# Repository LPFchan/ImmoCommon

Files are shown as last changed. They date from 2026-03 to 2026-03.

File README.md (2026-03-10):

# Immogen — Ninebot G30 BLE Immobilizer

**Immogen** is a three-part BLE immobilizer system for the Ninebot Max G30, consisting of **[Uguisu](https://github.com/LPFchan/Immogen/tree/main/Uguisu#readme)** (key fob), **[Guillemot](https://github.com/LPFchan/Immogen/tree/main/Guillemot#readme)** (deck receiver), and **[Whimbrel](https://github.com/LPFchan/Whimbrel)** (Web Serial provisioning app).

Guillemot sits inline between the battery and ESC via an XT60 splice. Without a valid BLE unlock from Uguisu, the scooter stays inoperable. Male/female pigtails keep the install reversible—no permanent modification required.

```
┌─────────────────┐       BLE advertisement        ┌──────────────────────┐
│  UGUISU (FOB)   │ ─────────────────────────────> │ GUILLEMOT (RECEIVER) │
│  XIAO nRF52840  │       (2.4 GHz, ~2 m)          │  XIAO nRF52840       │
└───────┬─────────┘                                └──────────┬───────────┘
        │                                                     │
        │                 ┌────────────────────┐              │
        └──────(USB-C)──> │ WHIMBREL (WEB APP) │ <──(USB-C)───┘
       (Provisioning)     │ Chrome / Edge      │    (Provisioning)
                          └────────────────────┘
```

## Repository Structure

| Path | Description |
| --- | --- |
| `Uguisu/` | Key fob — firmware, KiCad, BOM. Button press → 2 s BLE broadcast → sleep. [README](https://github.com/LPFchan/Immogen/tree/main/Uguisu#readme) |
| `Guillemot/` | Deck receiver — firmware, KiCad, BOM. Duty-cycled scan (5%), validates adverts → SR latch → power gate. [README](https://github.com/LPFchan/Immogen/tree/main/Guillemot#readme) |
| `lib/` | Shared C++ library: AES-128-CCM MIC, provisioning loop, LittleFS counter storage |
| `tools/` | LED visualizer, BLE timing simulator, buzzer tuner (HTML); MIC test vectors (`gen_mic.py`) |
| `logs/` | Technical writeups: architecture reviews, BLE power analysis, design decisions, migration guides, documentation reports |

## BLE Protocol

Advertisement-only; no persistent connection. Both devices share a company ID, a 2-byte magic prefix (`0x494D`), and a pre-shared key (PSK). Each advertisement carries a 13-byte payload after the manufacturer specific data header (company ID + magic):

| Offset | Size | Field | Purpose |
| --- | ---- | --- | --- |
| 0 | 4 | counter | Anti-replay, monotonic (AAD)|
| 4 | 1 | command | 0x01 = Unlock, 0x02 = Lock (Encrypted) |
| 5 | 8 | mic | AES-128-CCM auth tag |

## Quick Start

Pre-built firmware is available on the [Releases](https://github.com/LPFchan/Immogen/releases) page. Use [Whimbrel](https://github.com/LPFchan/Whimbrel) to flash and provision keys via Web Serial.

**Build from source:**

```bash
# Deck receiver
cd Guillemot/firmware && pio run

# Key fob
cd Uguisu/firmware && pio run
```

## Roadmap

- Uguisu enclosure CAD (3D print).
- First-build validation: PPK2 power, BLE range through deck, pre-charge waveform.

## Safety & Legal

- Prototype security/power-interrupt device. Use at your own risk.
- Not affiliated with Segway-Ninebot.
- **Do not test lock behavior while riding.**

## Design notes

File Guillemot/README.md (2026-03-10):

# Guillemot — Ninebot G30 BLE Immobilizer Receiver

Guillemot is the deck receiver in a three-part immobilizer system ([Uguisu](https://github.com/LPFchan/Immogen/tree/main/Uguisu) fob + [Whimbrel](https://github.com/LPFchan/Whimbrel) web app) for the Ninebot Max G30. It validates encrypted BLE advertisements from the fob and controls an SR latch that gates battery-to-ESC power via an inline XT60 splice. Male/female pigtails make it fully reversible—no permanent modification to the vehicle. Protocol and cryptography are handled by the shared [lib/](https://github.com/LPFchan/Immogen/tree/main/lib) in this monorepo ([Immogen](https://github.com/LPFchan/Immogen)).

---

## Hardware

### Placement

Mount Guillemot on the plastic underside of the deck for good 2.4 GHz RF.

### Components & BOM (~$20)

| Ref | Part | Notes | JLCPCB # | Cost |
| --- | --- | --- | --- | --- |
| U1 | XIAO nRF52840 | MCU: BLE scanning, latch control, buzzer PWM | Seeed | $8.23  |
| U2 | SN74LVC2G02DCTR | SR latch: Q = unlock. 10 nF + 100 kΩ differentiator for POR pulse | C94600 (ext.) | $0.53  |
| PS1 | TPSM365R6V3RDNR | Buck: 3–65 V in, 3.3 V/600 mA, 4 μA Iq. Feeds XIAO 3V3 directly.  | C18208843 (ext.) | $3.59  |
| Q1 | IPB042N10N3G | Main MOSFET: 100 V/137 A, D2PAK, low-side GND return | C69300 (ext.) | $0.75  |
| Q2 | AO3422 | Pre-charge FET, inrush ~0.8 A. Driven by latch Q. | C37130 (ext.) | $0.23  |
| Q3 | SI2309CDS | Bleeder P-FET: disconnects 10 kΩ bleeder when locked (0 μA) | C10493 (ext.) | $0.23  |
| Q4 | 2N7002 | Gate drive | C8545 | $0.01  |
| Q5, Q6 | MMBT3904 | Buzzer driver | C20526 | $0.02  |
| BZ1 | FUET-1230 | Buzzer: 12×12×3 mm SMD, 4 kHz. Driven by MMBT3904 | C391037 (ext.) | $0.47  |
| D1 | BZT52C12-7-F | 12 V Zener | C124196 (ext.) | $0.11  |
| D2 | BZT52C10-7-F | 10 V Zener | C155227 (ext.) | $0.10  |
| D3, D4 | 1N4148W | Gate isolation from buzzer rail sag | C81598 | $0.01  |
| D5 | SMBJ45A | 45 V TVS diode for transient suppression | C114005 (ext.) | $0.08  |
| C1 | 10 nF (0603) | POR pulse differentiator | C57112 | $0.003 |
| C2 | 100 µF (1210) | Bulk decoupling. EMK325ABJ107MM-P 16V X5R ±20% | C90143 (ext.) | $0.31  |
| C3, C4 | 1 µF (0603) | RC delay bypass, gate isolation | C15849 | $0.01  |
| R1–R3, R7 | 100 kΩ (0603) | Gate drive, pull-ups, RC delay (τ = 100 ms) | C25803 | $0.006 |
| R4 | 1 MΩ (0603) | P-FET gate pull-up | C22935 | $0.001 |
| R5 | 10 kΩ (0603) | Bleeder resistor | C25804 | $0.001 |
| R6 | 4.7 kΩ (0603) | Piezo buzzer discharge resistor | C23162 | $0.001 |
| R8 | 47 Ω 2 W (2512) | Pre-charge resistor, inrush ~0.77–0.89 A | C136992 (ext.) | $0.10  |
| TP1–5 | XT60 + 12 AWG | Pigtails and GND jumper | Generic | — |
| — | PCB | 54×34 mm, 2 oz outer | JLCPCB | $1.60  |

JLCPCB P&P for SMT. Hand-solder XIAO edges, XT60 pigtails, and the GND jumper.

### PCB Layout

4-layer, 54×34 mm, 2 oz outer copper, designed for 30 A continuous.

- **12 AWG GND jumper (critical):** Main battery return bypasses inner layers. Run an external silicone wire from the `BAT-` XT60 pad to the MOSFET source pad.
- **Power traces:** `+BATT` and `ESC-` as top-layer pours. No high-current vias.
- **Clearance:** ≥ 0.6 mm between 42 V power and 3.3 V logic.
- **Pre-charge trace:** Q2 → R8 → `ESC-` routed at **1.0 mm** to survive initial ~40 W inrush surge.
- **RF keepout:** Strip copper on all layers under the XIAO's BLE antenna trace.
- **Assembly:** Single-sided (F.Cu) SMT for easy JLCPCB PCBA.

### Operation

- **Unlock flow:** Uguisu advert → MCU validates → SET latch → Q HIGH → pre-charge 100 ms → MOSFET ON → buzzer tone.
- **Lock flow:** Uguisu advert → MCU validates → buzzer tone → RESET latch → Q LOW → P-FET OFF, pre-charge OFF → MOSFET OFF.
- **Power (locked):** ~306 μA (buck Iq + 5% duty-cycled scan + latch). At 306 μA, a G30 (15.3 Ah) would theoretically take ~5.7 years to drain; battery self-discharge (~12 months) dominates in practice. See `logs/15-BLE_POWER_ANALYSIS_AND_DOCUMENTATION_DISCREPANCY.md` for derivation.
- **Buzzer timing:** Unlock tone ~34 ms after 10 V rail up; lock tone before RESET.

### Design Notes

- **EasyEDA → KiCad:** Schematics and PCBs are designed in KiCad. [easyeda2kicad](https://github.com/wokwi/easyeda2kicad) is used to import symbols and footprints from EasyEDA/LCSC. Example: `easyeda2kicad --full --lcsc_id=Cxxxx` (replace `Cxxxx` with the LCSC part number).
- **AO3422:** 55 V Vds provides margin over the 42 V bus when locked.
- **Gate drive R (100 kΩ):** Protects the 2N7002 and BZT Zeners.
- **POR circuit (10 nF + 100 kΩ):** 1 ms RC differentiator—brief pulse zeros the latch at power-on.
- **RC delay (100 kΩ + 1 μF):** 1N4148W bypass for fast turn-off.
- **Gate isolation (1N4148W + cap):** Buzzer draw exceeds bleeder supply; diode and 1 μF hold cap prevent gate sag during tones (Vgs ≈ 9.3 V).
- **Gate pull-down (MMBT3904):** Via Q̄/RC, discharges hold cap for instant OFF.
- **IPB042N10N3G:** Outperforms TO-220 standing upright in sealed deck enclosures when thermal pad is stitched to B.Cu. **IPB035N10NF2S (3.5 mΩ)** is the long-term successor depending on LCSC stock.

---

## Software

### Firmware

[PlatformIO](https://platformio.org/) project in `firmware/`

Scanning is duty-cycled (25 ms every 500 ms, 5% duty) for reliable detection. P(detect) = 100% per button press because `scanWindow (25 ms) ≥ advInterval (20 ms)` guarantees full phase coverage. The receiver rejects any payload with an invalid AES-CCM MIC or a counter less than or equal to the last seen value (anti-replay). The receiver is also protected against MCU hangs by an 8-second hardware Watchdog Timer (WDT) which triggers a clean reboot without disrupting the latch state.

### Protocol

Validation and crypto via shared [lib/](https://github.com/LPFchan/Immogen/tree/main/lib). See [Immogen README § BLE Protocol](https://github.com/LPFchan/Immogen#ble-protocol) for full specification.

### Onboarding

Use [Whimbrel](https://github.com/LPFchan/Whimbrel) for both tasks:

- **Firmware flashing:** Web-based flasher via Web Serial. Enter bootloader mode with a double-tap on reset.
- **Key provisioning:** Connect via USB; Whimbrel injects the shared AES-128 key. Physical presence is required. The firmware has no serial commands to read the key back.

---

## Safety & Notes

- Prototype security and power-interrupt device. Use at your own risk.
- Do not test lock behavior while riding.
- Not affiliated with Segway-Ninebot.
- Avoid committing KiCad per-user state (`*.kicad_prl`) or lock files.

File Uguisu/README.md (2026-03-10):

# Uguisu — Ninebot G30 BLE Immobilizer Fob

Uguisu is the BLE key fob in a three-part immobilizer system ([Guillemot](https://github.com/LPFchan/Immogen/tree/main/Guillemot) receiver + [Whimbrel](https://github.com/LPFchan/Whimbrel) web app) for the Ninebot Max G30. It broadcasts short, encrypted BLE advertisements on button press to unlock or lock the vehicle. This repository contains the fob firmware and hardware design files. Protocol and cryptography via the shared [lib/](https://github.com/LPFchan/Immogen/tree/main/lib) in this monorepo ([Immogen](https://github.com/LPFchan/Immogen)).

---

## Hardware

### Components & BOM (~$10)

| Ref | Part | Notes | Source / LCSC | Cost  |
| --- | --- | --- | --- | ----- |
| U1 | XIAO nRF52840 | Castellated, 21×17.5 mm | Seeed/Amazon  | $6.00 |
| BAT | TW-502535 | 3.7V 400mAh LiPo | Generic | $2.00 |
| KEY1 | SKQGABE010 | Tactile Switch SMD-4P 5.2x5.2mm | C115351 | $0.11 |
| LED1 | XL-5050RGBC | SMD5050-6P RGB LED Common Anode | C2843868 | $0.05 |
| R1, R3 | 120 Ω | 0603WAF1200T5E, 100mW 1% (Blue/Green) | C22787 | <$0.01|
| R2 | 330 Ω | 0603WAF3300T5E, 100mW 1% (Red) | C23138 | <$0.01|
| — | Enclosure | ~50×35×12 mm, 3D-printed | Homemade | — |

Hand-solder XIAO and LiPo.

### PCB Design

KiCad (`hardware/Uguisu.kicad_sch` / `hardware/Uguisu.kicad_pcb`).

### GPIO

| Function | Pin | nRF P0.x | Notes |
| --- | --- | --- | --- |
| Button (KEY1) | D0  | P0.02 | Active-low, internal pull-up, wake-from-system-off |
| Blue (LED1) | D1  | P0.03 | LED1 pin 1, R1 120 Ω, active-low (sink) |
| Red (LED1) | D2  | P0.28 | LED1 pin 2, R2 330 Ω, active-low (sink) |
| Green (LED1)  | D3  | P0.29 | LED1 pin 3, R3 120 Ω, active-low (sink) |

### RGB LED Behaviour

| Situation | Color  | Pattern |
| --- | --- | --- |
| Unlock | Green  | Single pulse (fade-in/hold/fade-out) |
| Lock | Red | Single pulse (fade-in/hold/fade-out) |
| Serial provisioning | Blue | Repeating pulse loop |
| Low battery + Unlock | Green  | Rapid pulse loop for 2 s |
| Low battery + Lock | Red | Rapid pulse loop for 2 s |
| Fatal error (FS fail)  | Red | Fast blink + onboard LED |

All timing constants live in `firmware/include/led_effects.h`. Use `tools/led_visualizer.html` (repo root; open in any browser) to preview and fine-tune durations before flashing.

### Operation

- **Unlock flow:** Short press (< 0.7 s) → green flash → BLE broadcast ~2 s → sleep.
- **Lock flow:** Long press (≥ 0.7 s) → red flash → BLE broadcast ~2 s → sleep.
- **Low battery:** Battery checked after button press; replaces single flash with 2 s pulse loop in the same color while advertising.
- **Power:** ~30 μA standby (nRF52840 system-off + XIAO charging IC), ~0.006 mAh per press (12–18 months between charges on 400 mAh LiPo). Charging via USB-C.

### Design Notes

- **EasyEDA → KiCad:** Schematics and PCBs are designed in KiCad. [easyeda2kicad](https://github.com/wokwi/easyeda2kicad) is used to import symbols and footprints from EasyEDA/LCSC. Example: `easyeda2kicad --full --lcsc_id=Cxxxx` (replace `Cxxxx` with the LCSC part number).
- **NVS wear:** Counter written every press (System OFF kills RAM). At 10 unlocks/day, ~2.7 years; wear-leveling extends this.

---

## Software

### Firmware

[PlatformIO](https://platformio.org/) project in `firmware/`.

**Boot flow:**

```
led::init()
g_store.begin()          — fail → error_loop() [red rapid blink + onboard LED, forever]
load_provisioning()

VBUS present?
  yes → prov_led_task (blue pulse, FreeRTOS)
        ensure_provisioned()   [waits for PROV: serial packet]
        stop prov_led_task
        led::off()

Bluefruit.begin() / setName / setTxPower

wait_for_button_press_release(2 s)
  timeout → system_off()

command = press ≥ 0.7 s ? Lock : Unlock
cmd_pin = Lock ? PIN_LED_R : PIN_LED_G
low_bat = readVbat_mv() < LED_LOWBAT_MV_THRESHOLD

[crypto: nonce → msg → AES-128-CCM MIC]
  fail → system_off()

g_store.update(counter)
start_advertising_once()     — BLE advertising starts
adv_start = millis()

low_bat?
  yes → flash_low_battery(cmd_pin)   [~2 s repeating pulses, same color as command]
  no  → flash_once(cmd_pin, ...)     [~750 ms single pulse]

delay(UGUISU_ADVERTISE_MS - elapsed)   — wait out rest of advertising window

system_off()
```

Next press wakes via GPIO (hardware SENSE on `UGUISU_PIN_BUTTON_NRF`).

### Protocol

Generation and crypto via shared [lib/](https://github.com/LPFchan/Immogen/tree/main/lib). See [Immogen README § BLE Protocol](https://github.com/LPFchan/Immogen#ble-protocol) for full specification.

### Onboarding

Use [Whimbrel](https://github.com/LPFchan/Whimbrel) for both tasks:

- **Firmware flashing:** Web-based flasher via Web Serial. Enter bootloader mode with a double-tap on reset.
- **Key provisioning:** Connect via USB; Whimbrel injects the shared AES-128 key. Physical presence is required. The firmware has no serial commands to read the key back.

---

## Safety & Notes

- Prototype security device. Use at your own risk.
- Do not test lock behavior while riding.
- Not affiliated with Segway-Ninebot.
- Avoid committing KiCad per-user state (`*.kicad_prl`) or lock files.

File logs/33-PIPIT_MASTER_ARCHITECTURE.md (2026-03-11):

# Pipit Master Architecture (Phase 1)

*Date: 2026-03-10*

**Status:** Finalized Master Architecture
**Scope:** Complete architectural blueprint for the Pipit companion app, Guillemot firmware integration, Whimbrel dashboard, and the BLE security protocol. This document serves as the single source of truth, superseding logs 30, 31, and 32.

---

## 1. Overview & Tech Stack

**Pipit** is the companion app for the Immogen immobilizer ecosystem. It provides:
1. **Proximity Unlock (Background):** Low-power background BLE service that detects the vehicle and automatically unlocks Guillemot based on RSSI thresholding.
2. **Active Key Fob (Foreground):** Manual lock/unlock UI, functionally identical to the Uguisu hardware fob.

**Tech Stack:**
* **Kotlin Multiplatform (KMP):** Shared business logic (AES-CCM crypto, state management). Ported from the existing C++ `immo_crypto` logic to pure Kotlin and validated against existing test vectors.
* **Native UI:** **UIKit** (iOS) and **Jetpack Compose** (Android). Native toolkits are used to ensure reliable integration with OS-level BLE background modes, camera (QR scanning), and secure keystores.

---

## 2. Key Slot Architecture

Guillemot supports **4 key slots** (0–3), each with an independent 16-byte AES-CCM PSK, monotonic counter, and an optional 24-character human-readable device name (e.g., "Jamie's iPhone"). Slots are divided into three **access tiers** based on slot number:

| Slot | Tier | Default Name | Description |
|---|---|---|---|
| **0** | Hardware | `Uguisu` | Reserved for the Uguisu hardware fob. Lock/unlock only. No BLE management. USB-only administration. |
| **1** | Owner | *(set during onboarding)* | The primary phone. Full management access via SMP. Enforced as the first phone provisioned from Whimbrel. |
| **2** | Guest | `Guest 1` | Lock/unlock + restricted management. No PIN knowledge required. |
| **3** | Guest | `Guest 2` | Lock/unlock + restricted management. No PIN knowledge required. |

The tier is implicit from the slot number — no additional flags or metadata are stored. See Section 5.5 for the access control enforcement model.

*Why independent slots?* Sharing a single symmetric key across multiple active devices breaks the monotonic counter system, causing "Leapfrog Desyncs" where the phones continuously reject each other's payloads. Independent slots completely eliminate counter desyncs.

---

## 3. BLE Proximity Architecture

### 3.1 Flipped Roles & iBeacon Wake
Because iOS background advertising is broken (CoreBluetooth strips Manufacturer Data and hashes Service UUIDs into a proprietary format), the BLE roles are flipped from the Uguisu model:
* **Guillemot (Advertiser):** Broadcasts a continuous 500ms beacon as a connectable GATT peripheral.
* **Pipit (Scanner):** Registers a background scanner filtering for the Immogen Proximity UUID.

**iOS Background Optimization:** CoreBluetooth background scanning is throttled to ~3–4 minute intervals, which is unacceptable for proximity unlock. To mitigate this, Guillemot simultaneously broadcasts an **iBeacon** advertisement using a dedicated Immogen Proximity UUID (`66962B67-9C59-4D83-9101-AC0C9CCA2B12`). iOS CoreLocation monitors this beacon region via a hardware-level path, waking Pipit within ~1–2 seconds of approach. The nRF52840's extended advertising support allows both iBeacon and GATT advertisements to broadcast concurrently without alternation.

*   **iOS flow:** CoreLocation detects iBeacon region entry → wakes Pipit → Pipit initiates CoreBluetooth GATT connection → evaluates RSSI → sends payload.
*   **Android flow:** Foreground Service scans directly for the GATT advertisement (no iBeacon needed; Android background scanning is unrestricted).

**iOS Permission Requirement:** iBeacon region monitoring requires **"Always Allow" location permission**. Pipit must request this during onboarding. Users who decline are degraded to the slow CoreBluetooth background scanning path (~3–4 minute intervals). This trade-off should be communicated clearly in the permission prompt.

### 3.2 Stateful Proximity Beaconing
To support both "approach-to-unlock" and "walk-away-to-lock" without causing severe battery drain on the phone while riding, Guillemot dynamically changes its advertised Service UUID based on the latch state:

| State Beacon | UUID |
|---|---|
| **Immogen Proximity - Locked** | `C5380EF2-C3FC-4F2A-B3CC-D51A08EF5FA9` |
| **Immogen Proximity - Unlocked** | `A1AA4F79-B490-44D2-A7E1-8A03422243A1` |

*   **Approach (When Locked):** Guillemot advertises the Locked UUID. Pipit scans for this UUID. When detected, Pipit evaluates the RSSI against the unlock proximity threshold. If strong enough, it connects via GATT and sends the Unlock payload.
*   **Walk-Away (When Unlocked):** Guillemot switches to the Unlocked UUID. Pipit stops scanning for the Locked UUID (preventing redundant wakeups) and monitors the Unlocked UUID. When the RSSI drops below the lock proximity threshold (or the beacon drops entirely), it connects and sends the Lock payload.

### 3.3 RSSI Thresholds & Hysteresis
To prevent rapid lock/unlock cycling when the user hovers near the proximity boundary, the unlock and lock thresholds are separated by a 10 dBm hysteresis gap:
*   **Unlock threshold (default):** **-65 dBm** — phone must be close (~1–2 meters) to trigger unlock.
*   **Lock threshold (default):** **-75 dBm** — phone must move significantly farther away (~4–5 meters) before re-locking.

Both thresholds are user-configurable in Pipit's settings. The 10 dBm gap ensures that once unlocked, minor RSSI fluctuations from body movement, pocket placement, or multipath reflections do not trigger spurious re-locks.

---

## 4. GATT & Payload Protocols

### 4.1 GATT Service & Characteristic UUIDs

| Component | UUID |
|---|---|
| **Immogen Proximity Service** | `942C7A1E-362E-4676-A22F-39130FAF2272` |
| Unlock/Lock Command Characteristic | `2522DA08-9E21-47DB-A834-22B7267E178B` |
| Management Command Characteristic | `438C5641-3825-40BE-80A8-97BC261E0EE9` |
| Management Response Characteristic | `DA43E428-803C-401B-9915-4C1529F453B1` |

### 4.2 GATT Characteristic Structure
Guillemot's `Immogen Proximity` GATT service exposes three characteristics:

1.  **Unlock/Lock Command (Write Without Response):** Receives the 14-byte encrypted AES-CCM payload. Like the Uguisu hardware fob, this is a "fire-and-forget" blind write. No custom GATT error feedback is required.
2.  **Management Command (Write, Authenticated Link):** Gated by the 6-digit BLE Pairing PIN. Receives administrative commands (e.g., `PROV`, `REVOKE`, `RENAME`, `SLOTS?`).
3.  **Management Response (Notify):** Returns asynchronous responses to management commands. All responses are structured JSON (see Section 6).

**MTU Negotiation:** Management commands (e.g., `PROV` with a 32-character hex key + name) can exceed the default 23-byte ATT MTU. Guillemot requests an MTU exchange to 128 bytes upon connection. Pipit and Whimbrel (Web Bluetooth) must also request a larger MTU before sending management commands.

### 4.3 Payload Structure & Slot Identification
The 14-byte command payload structure is: `[1-byte Prefix (AAD)] [4-byte Counter (AAD)] [1-byte Command (Ciphertext)] [8-byte MIC]`.

The 1-byte Prefix carries only the Slot ID to route payloads to the correct AES key without brute-forcing decryption across all slots. The Command remains encrypted in the ciphertext to preserve confidentiality.
*   **`Prefix = (Slot_ID << 4)`**
*   **Upper 4 bits:** Target Key Slot (0-3).
*   **Lower 4 bits:** Reserved (zero).

*Example:* `0x10` instructs Guillemot to pull the AES key for Slot 1. The actual command (Unlock/Lock) is only revealed after successful AES-CCM decryption.

---

## 5. Security & Management PIN

### 5.1 The 6-Digit Management PIN
A 6-digit PIN is established during the initial USB-C setup. This PIN serves two roles:
1. **BLE Pairing PIN (SMP):** Used as the standard BLE Pairing PIN for authenticated management sessions.
2. **QR Key Encryption:** Used as the input to an Argon2id KDF to derive an AES-128 key that encrypts the slot key inside provisioning QR codes (see Section 7.1).

### 5.2 Security via BLE Pairing PIN (SMP)
The PIN is not sent as a custom plaintext payload. It acts as the **standard BLE Pairing PIN (SMP)**. When Pipit or Whimbrel attempts to access Management characteristics, the host OS (iOS/Android/Windows) natively prompts the user for the 6-digit PIN. This establishes a fully encrypted and MITM-protected BLE session before any sensitive data (like new AES root keys) is transmitted.

*Because the SoftDevice requires the plaintext PIN to execute the SMP mathematical handshake, the `SETPIN` command transmits and stores the 6 digits in plaintext.*

### 5.3 Brute-Force Rate Limiting
* Exponential backoff after 3 consecutive failures (5s → 10s → 20s → 40s → ...).
* Hard lockout after 10 consecutive failures (BLE management disabled entirely). Recovery requires USB-C serial via Whimbrel (`RESETLOCK` command, serial-only).

### 5.4 Counter Security Model
Each key slot maintains an independent strictly-monotonic counter. Guillemot rejects any payload where `counter <= last_seen_counter` for that slot. There is no tolerance window — this is by design. A single replayed or out-of-order payload is always rejected. This strict model is the core of the anti-replay security and eliminates the complexity of window-based counter acceptance.

### 5.5 Slot-Based Access Tiers & the `IDENTIFY` Command

Management access is gated by two layers: **SMP authentication** (the phone knows the 6-digit PIN) and **slot identity** (the phone proves which slot it owns). SMP gets you through the door; `IDENTIFY` determines what you can do inside.

**The `IDENTIFY` command:**
At the start of any management session, the phone sends an `IDENTIFY` payload — a standard 14-byte AES-CCM packet (same format as lock/unlock, Section 4.3) with command byte `0x02`. The prefix byte carries the claimed slot ID. Guillemot decrypts the payload using the claimed slot's key:
*   **MIC valid + counter valid →** Session is bound to that slot. Guillemot stores a `session_slot` variable for the lifetime of the GATT connection.
*   **MIC invalid →** Rejected. The session remains unbound and all subsequent management commands are refused.

The `IDENTIFY` payload uses the same counter as lock/unlock (incrementing the slot's monotonic counter). This is acceptable — one counter tick per management session is negligible.

**Unidentified sessions:** If a phone pairs via SMP but never sends `IDENTIFY` (or sends an invalid one), Guillemot refuses all management commands except `SLOTS?` (read-only, no harm). This means a guest phone that only knows the PIN but has no slot key gets no write access even if it manages to pair.

**Permission matrix (enforced in Guillemot's parser after `IDENTIFY`):**

| Command | Slot 1 (Owner) | Slot 2–3 (Guest) | No IDENTIFY |
|---|---|---|---|
| `IDENTIFY` | ✓ | ✓ | N/A |
| `SLOTS?` | ✓ | ✓ | ✓ (read-only fallback) |
| `PROV:<any>` | ✓ | ✗ | ✗ |
| `REVOKE:<any>` | ✓ | ✗ | ✗ |
| `RENAME:<own slot>` | ✓ | ✓ | ✗ |
| `RENAME:<other slot>` | ✓ | ✗ | ✗ |
| `SETPIN` | serial-only | serial-only | serial-only |
| `RESETLOCK` | serial-only | serial-only | serial-only |

**Guest access in practice:** Guest phones (Slot 2–3) provision via **unencrypted QR codes** (Section 7.1.1) and never learn the management PIN. They interact exclusively with the Unlock/Lock Command characteristic (Write Without Response, no SMP required). Their only management capability — renaming their own slot — requires the owner to share the PIN with them explicitly, which is an opt-in escalation rather than a default.

**Why not skip `IDENTIFY` and just use SMP bonds?** SMP bonds (LTK + IRK) are device-level — they prove "this phone paired before" but not "this phone owns Slot N." IRKs also break when the user clears Bluetooth data, re-pairs, or switches phones. The `IDENTIFY` command provides cryptographic proof of slot ownership that survives re-pairing and is unforgeable without the slot key.

---

## 6. Serial & Management Protocol

### 6.1 Command Transport
Commands are accepted over two transports with different permission levels:

| Command | USB-C Serial | BLE GATT (Authenticated) | Tier Gate |
|---|---|---|---|
| `IDENTIFY` (14-byte AES-CCM payload) | N/A | Yes | Any slot |
| `PROV:<slot>:<key>:<ctr>:[name]` | Yes | Yes | Owner only |
| `RENAME:<slot>:<name>` | Yes | Yes | Owner (any slot) · Guest (own slot) |
| `SLOTS?` | Yes | Yes | Any (incl. unidentified) |
| `REVOKE:<slot>` | Yes | Yes | Owner only |
| `SETPIN:<6digits>` | Yes | **No** (serial-only) | N/A |
| `RESETLOCK` | Yes | **No** (serial-only) | N/A |

`IDENTIFY` is sent as a 14-byte AES-CCM payload (same format as lock/unlock, command byte `0x02`) through the Management Command characteristic. It binds the BLE session to a slot and access tier (see Section 5.5). Must be sent before any write commands; only `SLOTS?` is allowed without identification.

`SETPIN` and `RESETLOCK` are restricted to USB-C serial because they are recovery/bootstrap operations. Exposing `RESETLOCK` over BLE would allow an attacker to clear brute-force lockout and keep attacking the PIN. `SETPIN` is serial-only to prevent remote PIN changes by a compromised phone.

### 6.2 Response Format
All management commands respond with structured JSON over both transports:

**Success responses:**
```json
{"status":"ok","slot":1,"name":"iPhone","counter":0}
```

**Error responses:**
```json
{"status":"error","code":"MALFORMED","msg":"invalid slot"}
```

**`SLOTS?` response:**
```json
{"status":"ok","slots":[
  {"id":0,"used":true,"counter":4821,"name":"Uguisu"},
  {"id":1,"used":true,"counter":127,"name":"iPhone"},
  {"id":2,"used":false,"counter":0,"name":""},
  {"id":3,"used":false,"counter":0,"name":""}
]}
```

---

## 7. Key Provisioning, Migration, and Recovery

### 7.1 Initial Provisioning — Owner (Whimbrel)
1. Flash Guillemot and Uguisu via USB-C.
2. Whimbrel asks user to set the 6-digit PIN (`SETPIN:123456`).
3. Whimbrel provisions Slot 1 (`PROV:1:<key>:0:iPhone`).
4. Whimbrel generates an **encrypted QR code:**
   * Derives an AES-128 key from the PIN using **Argon2id** (parameters: `m=262144` (256 MB), `t=3`, `p=1`, with a random 16-byte salt).
   * Encrypts the slot key using AES-CCM with the derived key.
   * QR contains: `immogen://prov?slot=1&salt=<hex>&ekey=<encrypted_key_hex>&ctr=0&name=iPhone`
   * The PIN is **never** included in the QR code.
5. User scans the QR on their phone. Pipit prompts for the 6-digit PIN, derives the same AES key via Argon2id, decrypts the slot key, and stores it in the platform's secure keystore.

*Security: Even if the QR code is photographed, the slot key cannot be recovered without the 6-digit PIN. Argon2id (256 MB) makes offline brute-force expensive (~800ms per guess on CPU, ~220 hours for 1M combinations; ~12 hours on a 10-GPU cluster).*

### 7.1.1 Guest Provisioning (Whimbrel or Pipit)
Guest slots (2–3) use **unencrypted QR codes**. The slot key is transmitted in plaintext within the QR payload — no Argon2id, no PIN.

1. The owner provisions a guest slot via Whimbrel (`PROV:2:<key>:0:Guest 1`) or via Pipit (Section 10.6).
2. The provisioning device generates a **plaintext QR code:**
   * QR contains: `immogen://prov?slot=2&key=<hex>&ctr=0&name=Guest%201`
   * Note: `key` field (plaintext) instead of `salt` + `ekey` (encrypted). The presence of `key` vs `ekey` tells the scanning phone whether to prompt for a PIN.
3. The guest scans the QR. Pipit detects the plaintext format, **skips the PIN prompt entirely**, stores the slot key directly in the secure keystore, and completes onboarding.

*Security trade-off: If the QR is photographed or intercepted, the attacker obtains the slot key and can lock/unlock the vehicle. This is accepted for guest slots because (a) QR exchange typically happens in person, (b) the owner can revoke a guest slot at any time, and (c) guest slots have no management privileges. The owner's Slot 1 key is never exposed via this path.*

### 7.2 The "Migration" Flow (Happy Path)
Used when a user is upgrading to a new phone and has both devices in hand.
1. The old phone generates an **encrypted QR code** containing its current Slot ID, AES Key, and **current Counter value**, encrypted with the user's PIN via Argon2id (same scheme as Section 7.1).
2. The new phone scans the QR, prompts the user for their PIN, decrypts the credentials, and takes over the counter exactly where the old phone left off.
3. The old phone instantly deletes the key from its local secure storage.
*Result: Instant transfer, zero counter desyncs, no BLE management interaction required. QR is safe even if intercepted.*

### 7.3 The "Recovery" Flow (Break-Glass Path)
Used when a phone is lost or destroyed. The user only needs their 6-digit BLE Pairing PIN.
1. The user installs Pipit on a new phone, connects to Guillemot, and authenticates using the PIN.
2. Pipit queries the slots (`SLOTS?`), and Guillemot returns a JSON array.
3. Pipit displays a UI: *"Which device did you lose?"* listing the names (e.g., "Jamie's iPhone").
4. The user selects "Jamie's iPhone" (Slot 1).
5. Pipit issues `REVOKE:1`, instantly locking out the stolen phone.
6. Pipit generates a random 16-byte AES key using the platform's secure random generator (`SecRandomCopyBytes` on iOS, `SecureRandom` on Android) and provisions itself into that vacated slot via `PROV:1:<new_key>:0:New iPhone`.
*Result: Securely locks out the old device and establishes a brand new cryptographic counter baseline.*

---

## 8. Platform Capability Matrix

| Operation | Pipit (Android) | Pipit (iOS) | Whimbrel (laptop) |
|---|---|---|---|
| **Guillemot firmware flash** | USB OTG (`.uf2` via `libaums`) | Not supported | USB-C DFU |
| **Uguisu firmware/key flash** | USB OTG (CDC serial via `usb-serial-for-android`) | Not supported | Web Serial |
| **Key management (BLE)** | BLE GATT + OS PIN Prompt | BLE GATT + OS PIN Prompt | Web Bluetooth + OS PIN Prompt |
| **Phone provisioning** | Encrypted QR scan + PIN entry | Encrypted QR scan + PIN entry | Web Bluetooth + Encrypted QR display |
| **Proximity unlock** | Background scan (Foreground Service) | iBeacon region monitoring (CoreLocation) + GATT | N/A |
| **Active key fob** | BLE GATT write | BLE GATT write | N/A |

---

## 9. Required Codebase Modifications

Implementing this architecture requires targeted updates across all four projects in the monorepo:

### 9.1 `ImmoCommon` (Shared Library)
*   **Struct Update (`immo_storage.h`):** Refactor the storage struct from a single key/counter into an array of 4 Key Slots. Each slot must contain an AES key array, a monotonic counter, and a `char name[24]` buffer. A clean reflash is acceptable for the storage migration (prototyping phase).
*   **Crypto Update (`immo_crypto.cpp`):** Update `verify_payload()` to extract the `Slot ID` using bitwise logic (`prefix >> 4`), validate that the target slot is active, and fetch the correct AES key from storage before executing the CCM MIC check.

### 9.2 `Guillemot` (Immobilizer Firmware)
*   **BLE Initialization (`main.cpp`):** Initialize dual BLE roles (`Central` + `Peripheral`).
*   **Stateful Beaconing:** Implement advertising logic to dynamically swap the Service UUID between `Locked` and `Unlocked` based on the latch state.
*   **GATT Server Setup:** Define the `Immogen Proximity` service. Add the `Unlock Command` (Write Without Response), `Management Command` (Write), and `Management Response` (Notify) characteristics.
*   **Security Manager (SMP):** Configure the SoftDevice security manager to require an Authenticated Link for the Management characteristics. Feed the plaintext 6-digit PIN from flash into the `ble_gap_opt_passkey_t` structure.
*   **iBeacon Advertising:** Add a concurrent iBeacon advertising set using the Immogen Proximity UUID (`66962B67-9C59-4D83-9101-AC0C9CCA2B12`) via the nRF52840's extended advertising support.
*   **Parser Expansion:** Update the serial parser to handle the new `RENAME` command, accept names in the `PROV` command, format `SLOTS?` output as JSON, and accept 6 plaintext digits for `SETPIN`. Route incoming GATT `Management Command` writes into this same parser. The parser must gate `SETPIN` and `RESETLOCK` to serial-only; reject these commands when the source is GATT (see Section 6.1).

### 9.3 `Uguisu` (Hardware Fob Firmware)
*   **Prefix Byte Packing:** Update the payload builder in `Uguisu/firmware/src/main.cpp` to explicitly pack `0x00` (Slot 0) into the upper 4 bits of the prefix byte when broadcasting, ensuring Guillemot routes the payload to the reserved hardware fob slot.

### 9.4 `Whimbrel` (Web Dashboard)
*   **Protocol Updates (`serial.js` / `api.js`):** Update the API wrappers to append device names to the `PROV` command, implement the `RENAME` command, and send `SETPIN` as plaintext digits instead of a hash.
*   **BLE Management (`js/`):** Implement Web Bluetooth to connect to the new GATT service, request access to the `Management Command` characteristic (triggering the browser's native PIN prompt), and listen to `Management Response` notifications.
*   **JSON Parsing:** Parse the JSON response from `SLOTS?` to populate the dashboard UI with slot IDs, usage status, and device names.
*   **UI & QR Updates (`app.js` / `prov.js`):** Add text fields for Device Name during the "Add Phone" wizard. Add an "Edit Name" button next to active slots in the dashboard view. Implement Argon2id KDF + AES-CCM encryption for QR code generation. The QR payload must contain the salt, encrypted key, counter, slot, and name — but never the PIN.

---

## 10. Pipit UI/UX Architecture

### 10.1 Navigation Model
Pipit uses a **single-screen utility model**. The Home screen (key fob) is always the root view. Settings is the only secondary surface — presented via a **3D flip transition** from the fob model (Section 10.4.2). All management flows (provisioning, migration, slot actions) are reached from within Settings. There are no tab bars, drawers, or deep navigation stacks.

**Theme:** System-follows (respects OS dark/light mode automatically).

### 10.2 Screen Inventory

```
┌──────────────────────────────────────────────────────────────────┐
│                        App Launch                                │
│                            │                                     │
│                 ┌──────────┴──────────┐                          │
│                 ▼                     ▼                          │
│       [No Key in Keystore]    [Key Exists in Keystore]           │
│                 │                     │                          │
│                 ▼                     ▼                          │
│         Onboarding Flow          Home Screen                     │
│         (Camera-first)               │                          │
│                 │              ⚙ flip transition                 │
│                 ▼                     ▼                          │
│            Home Screen           Settings                        │
│                                      ├── Proximity controls      │
│                                      ├── Key Slots (inline)      │
│                                      │    ├── ⋮ Rename           │
│                                      │    ├── ⋮ Replace ──▶ Replace Flow  │
│                                      │    ├── ⋮ Delete           │
│                                      │    └── ⊕ ──▶ Provision New Phone   │
│                                      ├── Transfer to New Phone   │
│                                      ├── USB Flashing (Android)  │
│                                      └── About                   │
└──────────────────────────────────────────────────────────────────┘
```

---

### 10.3 Onboarding Flow (First Launch Only)

Triggered when no AES key exists in the platform secure keystore. The camera opens **immediately** — no welcome preamble.

**Step 1 — QR Scan (Camera-First)**
```
┌─────────────────────────────┐
│                             │
│  ▓▓▓▓▓▓▓▓▓▓▓▓▓▓▓▓▓▓▓▓▓▓▓  │
│  ▓▓▓▓▓▓▓▓▓▓▓▓▓▓▓▓▓▓▓▓▓▓▓  │
│  ▓▓▓▓▓▓▓▓▓▓▓▓▓▓▓▓▓▓▓▓▓▓▓  │
│  ▓▓▓▓▓┌───────────┐▓▓▓▓▓▓  │
│  ▓▓▓▓▓│           │▓▓▓▓▓▓  │
│  ▓▓▓▓▓│  [camera] │▓▓▓▓▓▓  │
│  ▓▓▓▓▓│           │▓▓▓▓▓▓  │
│  ▓▓▓▓▓└───────────┘▓▓▓▓▓▓  │
│  ▓▓▓▓▓▓▓▓▓▓▓▓▓▓▓▓▓▓▓▓▓▓▓  │
│  ▓  Scan from Whimbrel    ▓  │
│  ▓▓▓▓▓▓▓▓▓▓▓▓▓▓▓▓▓▓▓▓▓▓▓  │
│  ▓▓▓▓▓▓▓▓▓▓▓▓▓▓▓▓▓▓▓▓▓▓▓  │
│                             │
│   recover key from lost phone >│
│                             │
└─────────────────────────────┘
```
*   The app launches directly into a **full-screen camera view** with a **darkened overlay** (semi-transparent black, ~70% opacity) covering the entire screen. A **rounded-rectangle transparent window** (QR-sized, centered) cuts through the overlay to form the viewfinder.
*   The instruction text *"Scan from Whimbrel"* sits inside the darkened overlay below the viewfinder.
*   **"recover key from lost phone >"** — a subtle text link at the bottom of the screen. Tapping it launches the Self-Provisioning Variant of the Replace Flow (Section 10.7), which connects directly to Guillemot via BLE management.
*   Non-Immogen QR codes (anything not starting with `immogen://prov?`) are **silently ignored** — the viewfinder simply continues scanning. No error toast or inline message.
*   On valid scan → Pipit inspects the QR payload format:
    *   **Encrypted QR** (has `salt` + `ekey` fields — owner/migration): Proceeds to Step 2 (PIN Entry).
    *   **Plaintext QR** (has `key` field — guest provisioning, Section 7.1.1): **Skips PIN entry entirely.** Stores the slot key directly in the secure keystore and jumps straight to the QR Decryption Animation (Step 3, with no KDF wait).

**Step 2 — PIN Entry (Owner Only — Skipped for Guest QR)**
```
┌─────────────────────────────┐
│                             │
│   Enter your 6-digit PIN    │
│                             │
│   This is the PIN you set   │
│   during Guillemot setup.   │
│                             │
│     ┌─┐┌─┐┌─┐┌─┐┌─┐┌─┐    │
│     │ ││ ││ ││ ││ ││ │    │
│     └─┘└─┘└─┘└─┘└─┘└─┘    │
│                             │
│        [ Confirm ]          │
│                             │
└─────────────────────────────┘
```
*   Pipit derives the AES-128 key from the entered PIN via Argon2id (using the salt from the QR payload) and attempts decryption.
*   **Wrong PIN:** Inline error — *"Incorrect PIN. Please try again."* (client-side only; no brute-force concern since the QR is local data).
*   **Correct PIN →** triggers the QR Decryption Animation (Step 3).

**Step 3 — QR Decryption Animation**

On successful PIN entry, a **~1 second visual animation** plays before revealing the result. This mirrors the AES key creation visualization used in Whimbrel.

The animation sequence:
1.  **Dissolve (0–400 ms):** The QR code image (still on screen from Step 1, or re-shown as a thumbnail) breaks apart into a particle field — individual modules scatter outward with randomised velocities and slight rotation. The particles are small squares matching the QR module grid.
2.  **Convergence (400–800 ms):** The scattered particles re-converge toward the center, collapsing into a tight cluster. As they converge, their color shifts from neutral (black/white QR modules) to the app's accent color.
3.  **Resolve (800–1000 ms):** The particle cluster snaps into a key icon (or lock icon) with a brief glow/pulse, signaling "decryption complete". A short haptic fires at the resolve point (`.medium` impact).

The animation is purely decorative — the actual Argon2id KDF + AES-CCM decryption runs concurrently during steps 1–2 and completes well before the animation ends. If KDF takes longer than expected on older hardware, the animation pauses at the convergence phase and holds until decryption finishes.

**Step 4 — Location Permission (iOS Only)**
```
┌─────────────────────────────┐
│                             │
│   Enable proximity unlock?  │
│                             │
│   Pipit can automatically   │
│   unlock your scooter when  │
│   you walk up to it.        │
│                             │
│   This requires "Always     │
│   Allow" location access    │
│   so the app can detect     │
│   your scooter in the       │
│   background.               │
│                             │
│   Your location is never    │
│   stored or transmitted.    │
│                             │
│   [ Enable Proximity ]      │
│   [ Skip for Now ]          │
│                             │
└─────────────────────────────┘
```
*   **"Enable Proximity"** → triggers the iOS `CLLocationManager.requestAlwaysAuthorization()` system prompt. On Android, this step is skipped (background scanning uses a Foreground Service with no special location permission).
*   **"Skip for Now"** → proximity unlock is disabled; the user can enable it later from Settings. The app still functions as a manual key fob.

**Step 5 — Done (Slot Overview)**
```
┌─────────────────────────────┐
│                             │
│            ✓                │
│                             │
│   You're all set.           │
│                             │
│   Slot 0   Uguisu       🔑 │
│   Slot 1   Jamie's iPhone ● │
│            OWNER            │
│   Slot 2   — empty —       │
│            GUEST            │
│   Slot 3   — empty —       │
│            GUEST            │
│                             │
│        [ Done ]             │
│                             │
└─────────────────────────────┘
```
*   Shows all 4 slots (0–3) with their current state and tier labels (`OWNER` / `GUEST`). The user's own slot is highlighted with a dot or accent indicator. This gives the user a first look at the full slot topology and access hierarchy.
*   Dismisses the onboarding modal and reveals the Home screen.

---

### 10.4 Home Screen (Key Fob)

The primary and only persistent screen. Stripped down to the essential interaction: the **3D Uguisu model** and the **gear icon**. All status indicators, labels, and toggles have been removed to keep the screen maximally clean.

```
┌─────────────────────────────┐
│ ⚙                          │
│                             │
│                             │
│                             │
│   ╔═══════════════════════╗  │
│   ║                       ║  │
│   ║   [Uguisu 3D model]   ║  │
│   ║   perspective, lit    ║  │
│   ║   LED: off (idle)      ║  │
│   ║                       ║  │
│   ║                       ║  │
│   ╚═══════════════════════╝  │
│     Tap · Hold to lock      │
│                             │
│                             │
│                             │
└─────────────────────────────┘
```

**Layout Elements:**

1.  **Gear Icon (top-left):** Opens Settings via the 3D flip transition (Section 10.4.2).
2.  **3D Uguisu Model (center, dominant):** A real-time photorealistic render of the Uguisu fob. This is the only interactive element on the screen.

    **Gesture model (mirroring the physical fob):**
    *   **Short press (tap):** Sends the **Unlock** AES-CCM payload.
    *   **Long press (~700 ms hold):** Sends the **Lock** AES-CCM payload automatically the instant the 700 ms threshold is reached — no release required. A haptic fires at the same moment the packet is sent.

    **Visual states (matching real Uguisu fire-and-forget behaviour — LED flashes once per action, never holds):**
    *   **Idle (locked or unlocked):** Model rendered under neutral ambient lighting. The Uguisu's RGB LED is unlit (dark). There is no persistent visual difference between locked and unlocked — the model looks the same at rest regardless of latch state.
    *   **Unlock flash (on tap):** Model physically depresses (a subtle 1–2 mm push-in animation on the tactile button geometry). LED flashes green once (fade in 100 ms, hold 200 ms, fade out 200 ms), then returns to dark. Model button springs back.
    *   **Lock flash (on 700 ms threshold):** Model depresses briefly. LED flashes red once (same fade in/hold/fade out timing as unlock). Then returns to dark. Model button springs back.
    *   **Proximity auto-action:** When the background service triggers an auto-unlock or auto-lock, the model briefly plays the corresponding button-press + LED flash animation (without user touch) to communicate what happened.

    **Passive interactivity:**
    *   The model responds to device gyroscope input with a subtle parallax tilt (±5°), giving a sense of physical depth. This is purely cosmetic and can be disabled in Settings for users who find it distracting.

3.  **Hint Label:** Below the model, a small secondary text label: *"Tap · Hold to lock"* (visible until the user performs their first intentional lock, then hidden permanently via `UserDefaults` / `SharedPreferences` flag).

---

### 10.4.1 Disconnect Overlay

When Guillemot is not reachable, the home screen shows a **full-screen semi-transparent overlay** instead of dimming the model. The overlay follows the system theme:
*   **Light mode:** White overlay, ~60% opacity.
*   **Dark mode:** Black overlay, ~60% opacity.

The Uguisu 3D model remains faintly visible beneath the overlay but is **non-interactive** (touch events are consumed by the overlay).

```
┌─────────────────────────────┐
│ ⚙                          │
│▒▒▒▒▒▒▒▒▒▒▒▒▒▒▒▒▒▒▒▒▒▒▒▒▒▒▒│
│▒▒▒▒▒▒▒▒▒▒▒▒▒▒▒▒▒▒▒▒▒▒▒▒▒▒▒│
│▒▒▒▒▒▒▒▒▒▒▒▒▒▒▒▒▒▒▒▒▒▒▒▒▒▒▒│
│▒▒▒▒▒▒▒▒▒▒▒▒▒▒▒▒▒▒▒▒▒▒▒▒▒▒▒│
│▒▒▒▒▒ ○ Disconnected ▒▒▒▒▒▒▒│
│▒▒▒▒▒▒▒▒▒▒▒▒▒▒▒▒▒▒▒▒▒▒▒▒▒▒▒│
│▒▒▒▒▒▒▒▒▒▒▒▒▒▒▒▒▒▒▒▒▒▒▒▒▒▒▒│
│▒▒▒▒▒▒▒▒▒▒▒▒▒▒▒▒▒▒▒▒▒▒▒▒▒▒▒│
│▒▒▒▒▒▒▒▒▒▒▒▒▒▒▒▒▒▒▒▒▒▒▒▒▒▒▒│
└─────────────────────────────┘
```

**States:**
*   `○ Disconnected` — Default when beacon is not detected. Shown as a centered label with a gray dot. No pulsing, no animation — the user can see at a glance that the scooter is out of range.
*   `✕ Bluetooth is off` — Shown when BLE is disabled system-wide. Tapping the label deep-links to the OS Bluetooth settings.

The overlay **fades out** (200 ms) as soon as the Guillemot beacon is detected and a GATT connection is established. The gear icon remains accessible above the overlay so the user can always reach Settings regardless of connection state.

---

### 10.4.2 Settings Transition (3D Flip)

Tapping the gear icon triggers a **3D flip animation** that transitions from the Home screen to the Settings view:

1.  **Flip (0–400 ms):** The Uguisu 3D model begins a 180° rotation around its vertical axis (Y-axis), as if the user is flipping the physical fob over to look at its back. The model simultaneously scales up slightly (~1.1×) to fill more of the screen.
2.  **Morph (400–600 ms):** As the model completes the flip and shows its "back", the back surface cross-fades into the Settings content pane. The rounded edges of the model's silhouette expand to become the Settings sheet's rounded corners.
3.  **Settle (600–700 ms):** The Settings pane is fully visible and interactive.

**Reverse transition (closing Settings):** Tapping the close button (✕) or swiping down plays the animation in reverse — the Settings pane compresses back into the model's silhouette, the model flips 180° back to its front face, and settles into the Home screen position.

The transition is implemented using the platform's native 3D transform APIs:
*   **iOS:** `CATransform3D` with perspective (`m34`) on a snapshot layer, cross-fading to the Settings `UIViewController`.
*   **Android:** `View.rotationY` with `cameraDistance` on a shared element transition between the Compose surfaces.

---

### 10.4.3 3D Model Asset & Rendering

**Model source:**
The 3D model is derived from the Uguisu enclosure CAD once it is finalized. The PCB footprint is known (~35 × 46 mm, r ~2 mm rounded corners) and the enclosure envelope is ~50 × 35 × 12 mm. Until the enclosure CAD is complete, a **development placeholder** — a rounded-rectangle slab at the correct dimensions with a visible PCB texture — is used so rendering infrastructure can be built and validated independently of enclosure design.

The final model must include:
*   The enclosure body with accurate surface finish (3D-printed texture or smooth depending on final print).
*   The tactile button (SKQGABE010, 5.2 × 5.2 mm) as a distinct depressible geometry.
*   The RGB LED (XL-5050RGBC, SMD5050) as a separate emissive mesh controlled at runtime.
*   USB-C port cutout on the appropriate edge.

**Asset formats:**
*   `.glb` (glTF Binary) — used by Android (Filament/SceneView).
*   `.usdz` — used by iOS (RealityKit). Converted from the master `.glb` via Apple's `Reality Converter` or `usdzconvert`.
*   Both formats are bundled in the app (not downloaded at runtime). Total combined size target: < 5 MB.

**Rendering stack (fully native — no KMP sharing possible):**

| Platform | Library | Notes |
|---|---|---|
| iOS | **RealityKit** (`ARView` in non-AR mode) | PBR materials, environment lighting, entity animation. Gyroscope via `CMMotionManager`. |
| Android | **SceneView** (Filament-based, maintained Sceneform successor) | PBR materials, IBL environment map. Gyroscope via `SensorManager`. |

**Lighting:** Both platforms use an Image-Based Lighting (IBL) environment map simulating an outdoor environment (overcast sky). This gives the plastic/metal surfaces on the model a realistic appearance without requiring dynamic scene lights.

**LED emissive control at runtime:**
The LED mesh has its emissive color and intensity driven by the app state machine — not baked into the asset. The LED is **off by default** and only fires during transient flash animations (matching Uguisu's fire-and-forget behaviour):
*   `idle` (locked or unlocked) → emissive intensity: 0.0 (off)
*   `unlock flash` → emissive color: `#00FF00`, intensity ramps 0→1.0→0 over 500 ms (fade in 100 ms, hold 200 ms, fade out 200 ms)
*   `lock flash` → emissive color: `#FF0000`, same intensity ramp as unlock

The LED mesh is named `led_rgb` in the glTF scene graph so both platform renderers can address it by name at load time.

---

### 10.4.4 Haptics & Sound

Every interaction with the Uguisu model produces both a haptic and an optional sound response. Sound playback is conditional on the device's silent mode — sound never plays if the user has silenced their device.

**Haptic schedule:**

| Event | iOS (`UIImpactFeedbackGenerator`) | Android (`HapticFeedbackConstants` / `VibrationEffect`) |
|---|---|---|
| **Short press registered (unlock)** | `.light` impact | `KEYBOARD_TAP` |
| **Long press fires at 700 ms (lock payload sent)** | `.heavy` impact | `HapticFeedbackConstants.CONFIRM` (API 30+) or 80 ms `VibrationEffect.createOneShot` |
| **Disconnect overlay tap (rejected)** | `UINotificationFeedbackGenerator` `.error` | `HapticFeedbackConstants.REJECT` (API 30+) or double-short `VibrationEffect` |
| **Proximity auto-action (background service)** | `.light` (fires when app is foregrounded and model animates) | Same |
| **QR decryption animation resolve** | `.medium` impact | `LONG_PRESS` |

The long press is a single haptic event at the 700 ms threshold — the moment the packet fires. There is no mid-hold tick because the action is already complete; the heavy impact *is* the confirmation.

**Sound design:**

Both sounds are short, low-frequency mechanical clicks recorded or synthesised to evoke a physical tactile switch — not a UI chime. They should feel like the SKQGABE010 button on the actual Uguisu hardware.

*   **Unlock click:** A crisp, bright click (~40 ms, fast attack, no tail). Analogous to a single button press.
*   **Lock clunk:** A slightly heavier, deeper click (~60 ms, marginally slower attack). The extra weight communicates "this is a more deliberate action" without being alarming.

**Silent mode handling:**

*   **iOS:** Audio is played via `AVAudioPlayer` with the session category set to `.ambient`. This category automatically respects the hardware silent switch — no explicit mute check required.
*   **Android:** Before playback, check `AudioManager.getRingerMode()`. Play only if the result is `RINGER_MODE_NORMAL`. In `RINGER_MODE_VIBRATE` or `RINGER_MODE_SILENT`, skip audio entirely (haptics still fire since vibration is not affected by ringer mode on most devices).

Sound assets are bundled in the app as short `.caf` (iOS) and `.ogg` (Android) files, targeting < 20 KB each.

---

### 10.5 Settings & Key Management

Revealed via the 3D flip transition from the Home screen (Section 10.4.2). Key management is **inline** — slot rows are embedded directly in the Settings view, not behind a separate screen. Accessing the KEYS section requires an active BLE management connection (authenticated via SMP PIN). If not already connected, Pipit initiates the connection and the OS prompts for the 6-digit PIN when the user scrolls to or interacts with the KEYS section.

```
┌─────────────────────────────┐
│  Settings                 ✕ │
│─────────────────────────────│
│                             │
│  PROXIMITY                  │
│  ┌─────────────────────────┐│
│  │ Background Unlock  [ON] ││
│  │─────────────────────────││
│  │ Unlock Distance   ━━●━━ ││
│  │ (~2m / -65 dBm)        ││
│  │─────────────────────────││
│  │ Lock Distance     ━●━━━ ││
│  │ (~5m / -75 dBm)        ││
│  └─────────────────────────┘│
│                             │
│  KEYS                       │
│  ┌─────────────────────────┐│
│  │ Slot 0  Uguisu     🔑 ⋮││  ← ⋮ on Android only
│  │─────────────────────────││
│  │ Slot 1  Jamie's iPhone ⋮││
│  │─────────────────────────││
│  │ Slot 2       ⊕          ││
│  │─────────────────────────││
│  │ Slot 3       ⊕          ││
│  └─────────────────────────┘│
│                             │
│  DEVICE                     │
│  ┌─────────────────────────┐│
│  │ Transfer to New Phone ▶ ││
│  │─────────────────────────││
│  │ Change PIN (USB)      ▶ ││  ← Android only
│  │─────────────────────────││
│  │ Flash Firmware (USB)  ▶ ││  ← Android only
│  └─────────────────────────┘│
│                             │
│  ABOUT                      │
│  ┌─────────────────────────┐│
│  │ Version            1.0  ││
│  └─────────────────────────┘│
│                             │
└─────────────────────────────┘
```

Pipit detects the current phone's slot tier at launch (from the stored slot ID) and renders the appropriate settings variant. The two layouts share the same flip transition and visual shell — only the content differs.

---

### 10.5.1 Owner Settings (Slot 1)

```
┌─────────────────────────────┐
│  Settings                 ✕ │
│─────────────────────────────│
│                             │
│  PROXIMITY                  │
│  ┌─────────────────────────┐│
│  │ Background Unlock  [ON] ││
│  │─────────────────────────││
│  │ Unlock Distance   ━━●━━ ││
│  │ (~2m / -65 dBm)        ││
│  │─────────────────────────││
│  │ Lock Distance     ━●━━━ ││
│  │ (~5m / -75 dBm)        ││
│  └─────────────────────────┘│
│                             │
│  KEYS                       │
│  ┌─────────────────────────┐│
│  │ Slot 0  Uguisu     🔑 ⋮││
│  │─────────────────────────││
│  │ Slot 1  Owner's iPhone  ││  ← own slot, no ⋮
│  │         OWNER           ││
│  │─────────────────────────││
│  │ Slot 2  Guest 1        ⋮││
│  │         GUEST           ││
│  │─────────────────────────││
│  │ Slot 3       ⊕          ││
│  │         GUEST           ││
│  └─────────────────────────┘│
│                             │
│  DEVICE                     │
│  ┌─────────────────────────┐│
│  │ Transfer to New Phone ▶ ││
│  │─────────────────────────││
│  │ Change PIN (USB)      ▶ ││  ← Android only
│  │─────────────────────────││
│  │ Flash Firmware (USB)  ▶ ││  ← Android only
│  └─────────────────────────┘│
│                             │
│  ABOUT                      │
│  ┌─────────────────────────┐│
│  │ Version            1.0  ││
│  └─────────────────────────┘│
│                             │
└─────────────────────────────┘
```

**Sections:**

1.  **Proximity**
    *   **Background Unlock toggle:** Enables/disables the background BLE scanning service. On iOS, toggling ON checks location permission and prompts if not yet granted.
    *   **Unlock Distance slider:** Maps to the RSSI unlock threshold. Displayed in human-readable terms ("~2m") with the raw dBm value below. Range: -50 to -85 dBm. Default: -65 dBm.
    *   **Lock Distance slider:** Maps to the RSSI lock threshold. Range: -60 to -95 dBm. Default: -75 dBm.
    *   **Validation:** The lock threshold must always be at least 10 dBm below the unlock threshold (enforcing the hysteresis gap from Section 3.3). If the user drags one slider past the constraint, the other slider auto-adjusts.

2.  **Keys (Inline Key Management)**

    On first render, Pipit queries `SLOTS?` via the Management Command characteristic (triggering SMP pairing + `IDENTIFY` if not already connected) and populates the slot rows from the JSON response. Rows are always shown for all 4 slots. Each phone slot (1–3) displays a **tier label** below the device name — `OWNER` or `GUEST` in small caps, muted secondary color — so the owner can see the access hierarchy at a glance.

    *   **Slot 0 (Uguisu):** Shown with a key icon (🔑) and the name "Uguisu".
        *   **iOS:** Non-interactive. A subtle label *"Manage via Whimbrel"* indicates USB management is not available on iOS.
        *   **Android:** A **three-dot menu (⋮)** with:
            *   **Replace** — For swapping in a new physical Uguisu unit. Prompts the user to connect the new fob via USB-C OTG, then provisions a fresh Slot 0 key via CDC serial (`PROV:0:<new_key>:0:Uguisu`). The old fob is immediately locked out.
            *   No Rename or Delete options. The hardware fob's name is always "Uguisu" and Slot 0 cannot be vacated.

    *   **Slot 1 (owner's own slot):** Shows the slot number and device name. **No three-dot menu** — the owner cannot replace or delete their own slot from here. Use "Transfer to New Phone" in the DEVICE section to migrate.

    *   **Active guest slots (2–3):** Show the slot number and device name. A **three-dot menu button (⋮)** with:
        *   **Rename** — Opens a text input dialog (max 24 characters). On confirm, sends `RENAME:<slot>:<new_name>`.
        *   **Replace** — Launches the Replace Flow (Section 10.7). Revokes this slot and provisions a new phone in its place.
        *   **Delete** — Confirmation dialog: *"Revoke <name>? This device will be permanently locked out."* On confirm, sends `REVOKE:<slot>`. The row transitions to an empty-slot state.

    *   **Empty guest slots (2–3):** Show only a centered **⊕** icon. Tapping the row launches the Provision Guest Phone flow (Section 10.6).
    *   **Empty Slot 1:** Should not normally occur (Slot 1 is provisioned during initial Whimbrel setup). If it somehow appears empty, the ⊕ icon is not shown — Slot 1 can only be provisioned via Whimbrel.

3.  **Device**
    *   **Transfer to New Phone →** launches the Migration Flow (Section 10.8). This is the happy-path device upgrade where the owner has both phones in hand.
    *   **Change PIN (USB) →** *(Android only, hidden on iOS)* launches the Change PIN flow (Section 10.9). Requires USB-C OTG connection to Guillemot since `SETPIN` is serial-only (Section 6.1). On iOS, users must change the PIN via Whimbrel.
    *   **Flash Firmware (USB) →** *(Android only, hidden on iOS)* launches the USB Flashing flow (Section 10.10). Covers Guillemot `.uf2` flashing and Uguisu CDC serial provisioning.

4.  **About**
    *   App version, build number. Tap-and-hold for debug info (BLE state, stored slot ID, counter value).

---

### 10.5.2 Guest Settings (Slot 2–3)

A stripped-down variant with no key management, no USB operations, and no PIN access. The guest controls only their local proximity preferences and can transfer their own key.

```
┌─────────────────────────────┐
│  Settings                 ✕ │
│─────────────────────────────│
│                             │
│  PROXIMITY                  │
│  ┌─────────────────────────┐│
│  │ Background Unlock  [ON] ││
│  │─────────────────────────││
│  │ Unlock Distance   ━━●━━ ││
│  │ (~2m / -65 dBm)        ││
│  │─────────────────────────││
│  │ Lock Distance     ━●━━━ ││
│  │ (~5m / -75 dBm)        ││
│  └─────────────────────────┘│
│                             │
│  YOUR KEY                   │
│  ┌─────────────────────────┐│
│  │ Slot 2 · Guest 1       ││
│  │ Transfer to New Phone ▶ ││
│  └─────────────────────────┘│
│                             │
│  ABOUT                      │
│  ┌─────────────────────────┐│
│  │ Version            1.0  ││
│  └─────────────────────────┘│
│                             │
└─────────────────────────────┘
```

**Sections:**

1.  **Proximity** — Identical to owner. These are phone-local settings (stored in `UserDefaults` / `SharedPreferences`) and don't touch management. Guests have full control over their own proximity unlock behaviour.

2.  **Your Key** — A single-row section showing the guest's own slot ID and name. No three-dot menu, no slot list, no visibility into other slots.
    *   **Transfer to New Phone →** launches the Migration Flow (Section 10.8). The guest can migrate their own key to a new phone via QR. Since guest slots use plaintext QR (Section 7.1.1), the migration QR is also **unencrypted** — no PIN prompt during transfer.

3.  **About** — Same as owner. Tap-and-hold for debug info.

---

### 10.6 Provision Guest Phone Flow

Launched from Settings by tapping an **empty guest slot row (⊕)** (Slot 2 or 3). Since guest slots use unencrypted QR codes (Section 7.1.1), this flow requires **no PIN entry** from either party.

**Step 1 — Confirm**
```
┌─────────────────────────────┐
│                             │
│   Add a guest key?          │
│                             │
│   This will create a key    │
│   for Slot 2 (Guest 1).    │
│   The guest will be able    │
│   to lock and unlock only.  │
│                             │
│        [ Create Key ]       │
│        [ Cancel ]           │
│                             │
└─────────────────────────────┘
```
*   The target slot and default name are pre-determined: Slot 2 → "Guest 1", Slot 3 → "Guest 2".
*   No name input prompt. The owner can rename the slot later from the three-dot menu if desired.

**Step 2 — Provisioning & QR Generation**

Pipit executes the following automatically:
1.  Generates a random 16-byte AES key using the platform's secure random generator (`SecRandomCopyBytes` on iOS, `SecureRandom` on Android).
2.  Sends `PROV:<slot>:<key>:0:Guest 1` via the Management Command characteristic.
3.  Generates a **plaintext QR code**: `immogen://prov?slot=2&key=<hex>&ctr=0&name=Guest%201`

**Step 3 — QR Display**
```
┌─────────────────────────────┐
│                             │
│   Scan this on the          │
│   guest's phone             │
│                             │
│   ┌───────────────────┐     │
│   │                   │     │
│   │    [QR Code]      │     │
│   │                   │     │
│   └───────────────────┘     │
│                             │
│   The guest just needs to   │
│   scan — no PIN required.   │
│                             │
│        [ Done ]             │
│                             │
└─────────────────────────────┘
```
*   The QR contains the slot key in plaintext. No PIN is needed by the recipient.
*   **"Done"** dismisses the flow and returns to Settings. The slot row now shows "Guest 1" with an active indicator.

---

### 10.7 Replace Flow

Launched from the **three-dot menu → Replace** on an active slot that is *not* the user's own. This is the break-glass path for replacing a lost or compromised device. It combines revocation + provisioning + QR generation in a single sequence.

**Step 1 — Confirm Revocation**
```
┌─────────────────────────────┐
│                             │
│   ⚠ Replace "Jamie's       │
│   iPhone" (Slot 1)?         │
│                             │
│   This will permanently     │
│   lock out the old device   │
│   and create a new key      │
│   for a replacement phone.  │
│                             │
│   [ Replace ]               │
│   [ Cancel ]                │
│                             │
└─────────────────────────────┘
```

**Step 2 — Revoke, Provision & QR Generation**

Pipit executes automatically:
1.  `REVOKE:<slot>` — invalidates the old key.
2.  Generates a new random 16-byte AES key.
3.  `PROV:<slot>:<new_key>:0:<default_name>` — provisions the slot with the new key, counter reset to 0. Name is restored to the slot's default ("Guest 1" / "Guest 2" for guest slots; owner can edit after).
4.  Generates QR:
    *   **Guest slot (2–3):** Plaintext QR (no PIN, no Argon2id). `immogen://prov?slot=2&key=<hex>&ctr=0&name=Guest%201`
    *   **Owner slot (1):** PIN-encrypted QR (Argon2id, same as Section 7.1). Prompts the owner for their PIN before generating.

**Step 3 — QR Display**
*   Same layout as Provision Flow Step 3. For guest replacements, the display notes *"No PIN required."* For owner replacement, it notes the recipient will need the PIN.
*   **"Done"** returns to Settings. The slot row shows the default name.

**Self-Provisioning Variant:** When the Replace flow is entered from the **Onboarding camera screen → "Phone recovery >"**, the current phone has no key and needs to provision *itself* rather than generating a QR for another device. In this case:
1.  Pipit connects to Guillemot and authenticates via SMP PIN (OS prompt).
2.  Pipit queries `SLOTS?` and displays the active phone slots for the user to choose which device to replace.
3.  After revocation + provisioning, the new key is stored directly in the local secure keystore (no QR needed — the key is for this phone).
4.  Pipit proceeds to the onboarding Done screen (Step 5).

---

### 10.8 Migration Flow (Transfer to New Phone)

Launched from Settings → "Transfer to New Phone". This is the happy-path device upgrade described in Section 7.2. The user has both phones in hand.

**Step 1 — Confirm Intent**
```
┌─────────────────────────────┐
│                             │
│   Transfer your key to a    │
│   new phone?                │
│                             │
│   This will generate a QR   │
│   code for your new phone   │
│   to scan. After the        │
│   transfer, this phone      │
│   will no longer work as    │
│   a key.                    │
│                             │
│   [ Generate QR Code ]      │
│   [ Cancel ]                │
│                             │
└─────────────────────────────┘
```

**Step 2 — PIN Entry (Owner Only)**
*   **Owner (Slot 1):** Standard 6-digit PIN input. The PIN derives the Argon2id encryption key for the QR payload. Proceeds to Step 3.
*   **Guest (Slot 2–3):** This step is **skipped entirely**. The migration QR for guest slots is plaintext (same as Section 7.1.1) — no PIN needed. Proceeds directly to Step 3.

**Step 3 — QR Display**
```
┌─────────────────────────────┐
│                             │
│   Scan this on your         │
│   new phone                 │
│                             │
│   ┌───────────────────┐     │
│   │                   │     │
│   │    [QR Code]      │     │
│   │                   │     │
│   └───────────────────┘     │
│                             │
│   Open Pipit on your new    │
│   phone and scan this code. │
│                             │
│   [ Done — I've Scanned ]   │
│   [ Cancel ]                │
│                             │
└─────────────────────────────┘
```
*   The QR encodes the `immogen://prov?` URI with the encrypted slot key, **current counter value**, slot ID, name, and Argon2id salt. The counter is included so the new phone picks up exactly where the old phone left off (no desync).

**Step 4 — Confirmation & Key Deletion**
*   Tapping **"Done — I've Scanned"** triggers a confirmation dialog: *"Are you sure? The key will be permanently deleted from this phone."*
*   On confirm: the slot key is deleted from the secure keystore. Pipit returns to the Onboarding camera screen (it no longer has a valid key).
*   **"Cancel"** at any point aborts without deleting anything.

---

### 10.9 Change PIN (Android Only)

Launched from Settings → "Change PIN (USB)". Requires a USB-C OTG connection to Guillemot because `SETPIN` is a serial-only command (Section 6.1). This flow is **hidden on iOS** — iOS users must change the PIN via Whimbrel.

**Step 1 — Connect Guillemot via USB**
```
┌─────────────────────────────┐
│                             │
│   Change Management PIN     │
│                             │
│   Connect Guillemot via     │
│   USB-C OTG to continue.    │
│                             │
│       ○ Waiting for USB...  │
│                             │
└─────────────────────────────┘
```
*   Pipit listens for a CDC serial device via `usb-serial-for-android`. On detection: *"Guillemot connected."* Proceeds to Step 2.

**Step 2 — Enter New PIN**
```
┌─────────────────────────────┐
│                             │
│   Enter new 6-digit PIN     │
│                             │
│     ┌─┐┌─┐┌─┐┌─┐┌─┐┌─┐    │
│     │ ││ ││ ││ ││ ││ │    │
│     └─┘└─┘└─┘└─┘└─┘└─┘    │
│                             │
│   Confirm new PIN           │
│                             │
│     ┌─┐┌─┐┌─┐┌─┐┌─┐┌─┐    │
│     │ ││ ││ ││ ││ ││ │    │
│     └─┘└─┘└─┘└─┘└─┘└─┘    │
│                             │
│        [ Change PIN ]       │
│        [ Cancel ]           │
│                             │
└─────────────────────────────┘
```
*   Two-field entry with confirmation. Both must match to proceed.

**Step 3 — Confirmation**
*   Pipit sends `SETPIN:<6digits>` via USB serial.
*   On success: *"PIN changed. All phones will need the new PIN to pair for management in future sessions."*
*   **Important note displayed:** *"Existing BLE bonds are not affected. Phones that are already paired will continue to work. The new PIN is only needed when a phone pairs for management access for the first time, or after clearing its Bluetooth pairing data."*

---

### 10.10 USB Flashing (Android Only)

Launched from Settings → "Flash Firmware (USB)". This section is **hidden entirely on iOS** since iOS does not support USB OTG host mode for UF2 mass storage or CDC serial.

```
┌─────────────────────────────┐
│  ◀ Flash Firmware           │
│─────────────────────────────│
│                             │
│   Connect your device       │
│   via USB-C OTG.            │
│                             │
│  ┌─────────────────────────┐│
│  │                         ││
│  │  [ Flash Guillemot ]    ││
│  │  .uf2 firmware update   ││
│  │                         ││
│  └─────────────────────────┘│
│  ┌─────────────────────────┐│
│  │                         ││
│  │  [ Flash Uguisu ]       ││
│  │  firmware + key flash   ││
│  │                         ││
│  └─────────────────────────┘│
│                             │
└─────────────────────────────┘
```

**10.10.1 Flash Guillemot (UF2)**

Flashes the Guillemot immobilizer firmware via USB OTG using the UF2 mass storage protocol.

1.  The user connects Guillemot to the Android phone via USB-C OTG cable and boots Guillemot into UF2 bootloader mode (double-tap reset).
2.  Pipit detects the UF2 mass storage volume via `libaums` (USB mass storage library for Android) and displays: *"Guillemot bootloader detected."*
3.  Pipit provides a file picker to select the `.uf2` firmware file, or bundles the latest firmware in the app assets.
4.  **"Flash"** → Pipit copies the `.uf2` file to the root of the mass storage volume. Guillemot automatically reboots with the new firmware.
5.  Progress bar during file copy. On completion: *"Guillemot firmware updated."*

**10.10.2 Flash Uguisu (CDC Serial)**

Flashes the Uguisu hardware fob firmware and provisions its Slot 0 key via USB OTG CDC serial.

1.  The user connects the Uguisu fob (via its XIAO nRF52840 USB-C) to the Android phone via USB-C OTG cable.
2.  Pipit opens a CDC serial connection using `usb-serial-for-android` and detects the Uguisu bootloader or serial console.
3.  **Firmware flash:** Pipit sends the compiled firmware binary via the nRF52840's serial DFU protocol. Progress bar during transfer.
4.  **Key provisioning:** After firmware flash (or if firmware is already current), Pipit can send serial commands to configure Uguisu's Slot 0 AES key. This is typically done during initial setup and matches the `PROV:0:<key>:0:Uguisu` command format.
5.  On completion: *"Uguisu firmware updated and key provisioned."*

---

### 10.11 State Diagram — Home Screen

The Home screen 3D model and disconnect overlay reflect a combined state machine:

```
                    ┌──────────────────┐
          ┌────────▶│  Disconnected    │◀─── No beacon detected
          │         │  Overlay: ON     │
          │         │  Model: frozen   │
          │         └──────┬───────────┘
          │                │ Beacon detected + GATT connected
          │                ▼
          │         ┌──────────────────┐
          │    ┌───▶│  Connected       │
          │    │    │  + Locked        │
          │    │    │  Overlay: OFF    │
          │    │    └──────┬───────────┘
          │    │           │ User tap OR RSSI ≥ unlock threshold
          │    │           ▼
          │    │    ┌──────────────────┐
          │    │    │  Connected       │
          │    │    │  + Unlocked      │
          │    │    │  LED: off (idle) │
          │    │    └──────┬───────────┘
          │    │           │ User long press OR RSSI ≤ lock threshold
          │    │           │   OR beacon lost
          │    └───────────┘
          │                │ Beacon lost entirely
          └────────────────┘
```

**Key behaviors:**
*   The 3D model's LED is always off at rest — there is no persistent visual for lock/unlock state. The lock/unlock state is tracked internally and inferred from the Guillemot beacon UUID (Locked UUID vs Unlocked UUID, Section 3.2), but the model only shows LED flashes during actions.
*   When proximity mode is ON, the model plays the corresponding flash animation when a background service action fires (e.g., if the background service auto-unlocked while the app is foregrounded, the model plays the green flash).
*   The disconnect overlay and model interaction are driven by the same BLE event stream — there is no separate "manual mode" vs "proximity mode" state machine. Proximity mode simply automates the same gesture based on RSSI.

---

### 10.12 Error & Edge Case Handling

| Scenario | Behavior |
|---|---|
| **BLE off** | Disconnect overlay shows `✕ Bluetooth is off`. Tapping deep-links to OS Bluetooth settings. |
| **Location permission denied (iOS)** | Proximity toggle in Settings shows a warning: *"Proximity unlock requires 'Always Allow' location. Tap to open Settings."* The app still works as a manual key fob. |
| **Guillemot not found** | Disconnect overlay shows `○ Disconnected`. No timeout — overlay stays until beacon is detected. |
| **Management connection rejected (wrong PIN)** | OS-level SMP failure. Pipit shows: *"Pairing failed. Check your PIN and try again."* After 10 failures, Guillemot enters hard lockout (Section 5.3). Pipit shows: *"Device locked. Connect via USB to reset."* |
| **All phone slots full (provision attempt)** | All ⊕ rows are replaced by active device rows. The user must **Delete** an existing slot before provisioning a new phone. No empty slot = no ⊕ icon shown. |
| **Replace own slot attempted (owner)** | The **Replace** and **Delete** options are hidden in the three-dot menu for the owner's own slot (Slot 1). The owner must use "Transfer to New Phone" instead. |
| **Guest attempts restricted action** | If a guest somehow reaches a restricted management command (e.g., via a race condition or protocol manipulation), Guillemot returns `{"status":"error","code":"FORBIDDEN","msg":"guest slot"}`. Pipit shows: *"This action requires owner access."* |
| **IDENTIFY fails (wrong key / corrupted keystore)** | Guillemot returns MIC failure. Pipit shows: *"Identity verification failed. Your key may be corrupted. Contact the device owner."* Management session remains unbound. |
| **QR scan fails repeatedly** | After 3 failed scans, show a help link: *"Having trouble? Make sure the QR code is well-lit and fully visible."* |
| **Argon2id KDF slow on old hardware** | QR decryption animation pauses at the convergence phase and holds until KDF completes. No timeout — the animation simply waits. |
| **USB OTG device not detected (Android)** | Flash Firmware screen shows: *"No device detected. Make sure it's connected via USB-C OTG and in bootloader mode."* |
| **Change PIN — USB disconnected mid-write** | Pipit shows: *"Connection lost. PIN may not have been saved. Reconnect and try again."* The old PIN remains valid unless `SETPIN` succeeded before disconnect. |
| **Slot 0 Replace — Uguisu not connected via USB (Android)** | The Replace action prompts: *"Connect the new Uguisu fob via USB-C OTG."* Waits for USB detection before proceeding. |
| **Counter overflow** | The 4-byte counter supports ~4 billion operations. No UI handling needed for practical use. |

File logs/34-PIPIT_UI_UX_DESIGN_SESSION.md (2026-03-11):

# Pipit UI/UX Design Session — Summary

*Date: 2026-03-11*

**Context:** Iterative design session defining the complete UI/UX architecture for the Pipit companion app, filling the last major gap in the master architecture doc (log 33). This session also surfaced and resolved a multi-user access control model that fed back into the core protocol design (Sections 2, 5, 6, 7 of log 33).

---

## 1. Foundation Decisions

Three initial design questions were resolved:

| Decision | Choice |
|---|---|
| Navigation model | Single-screen + modal sheets (utility app feel, not tab bar) |
| Primary interaction | Single toggle button (later evolved into 3D model) |
| Theme | System-follows (auto dark/light) |

---

## 2. 3D Uguisu Model as Primary Interface

The flat lock/unlock toggle button was replaced with a **photorealistic 3D model of the Uguisu hardware fob** as the home screen's sole interactive element. This reinforces the mental model that Pipit *is* the fob.

**Interaction:**
- **Tap** → Unlock (fire-and-forget AES-CCM payload)
- **Long press (700 ms)** → Lock (fires automatically at threshold, no release needed — matching `UGUISU_LONG_PRESS_MS` in firmware)

**Visual behaviour matches real Uguisu fire-and-forget:**
- LED is **always off at rest** — no persistent locked/unlocked visual distinction
- Unlock → green LED flash once (100 ms in, 200 ms hold, 200 ms out), button depresses, springs back
- Lock → red LED flash once, same timing
- No radial progress ring during long press (rejected as a design element)

**Rendering:** RealityKit (iOS) / SceneView+Filament (Android). `.usdz` + `.glb` assets. IBL environment lighting. LED is a separately addressable emissive mesh (`led_rgb`) controlled at runtime. Gyroscope parallax tilt (±5°, optional). Model depends on enclosure CAD (TBD); dev placeholder uses PCB dimensions.

**Haptics & sound:** Single heavy haptic at 700 ms lock threshold. Light haptic on tap unlock. Mechanical click sounds (~40–60 ms) mimicking SKQGABE010 tactile switch. Sound respects silent mode (`.ambient` session category on iOS, `getRingerMode()` check on Android).

---

## 3. Home Screen — Stripped Clean

All status text, slot labels, and proximity toggles were removed from the home screen. Only three elements remain:

1. **Gear icon** (top-left) → opens Settings
2. **3D Uguisu model** (center) → lock/unlock
3. **Hint label** ("Tap · Hold to lock") → shown until first lock, then hidden permanently

**Disconnect overlay:** When Guillemot is out of range, a system-theme-colored semi-transparent overlay (white 60% in light mode, black 60% in dark mode) covers the screen with "○ Disconnected" centered. Model visible but non-interactive beneath. Gear icon remains accessible above overlay.

**Settings transition:** Tapping the gear icon triggers a 3D flip animation — the Uguisu model rotates 180° on Y-axis, its back face cross-fades into the Settings content pane. Reverse on close.

---

## 4. Onboarding — Camera-First

Steps 1 (welcome) and 2 (QR scan) were merged. The app launches **directly into a full-screen camera** with a darkened overlay and a transparent QR-sized viewfinder window.

- Instruction text: *"Scan from Whimbrel"*
- Recovery link: *"recover key from lost phone >"* (bottom, subtle)
- Non-Immogen QR codes are **silently ignored** (no error toast)
- QR format detection determines flow branching:
  - Encrypted QR (`salt` + `ekey` fields) → PIN entry → Argon2id decryption
  - Plaintext QR (`key` field, guest provisioning) → skip PIN entirely

**QR decryption animation (~1s):** Dissolve (QR modules scatter as particles) → Convergence (particles re-converge, color-shift to accent) → Resolve (snap into key icon, haptic). KDF runs concurrently; animation pauses if hardware is slow.

**Location permission (iOS only):** Explains "Always Allow" requirement for iBeacon proximity unlock. Can be skipped.

**Done screen:** Shows all 4 slots (0–3) with tier labels (`OWNER` / `GUEST`) and the user's slot highlighted.

---

## 5. Access Tier Model

Emerged from a discussion about multi-user PIN management. The core realization: the 6-digit management PIN gates SMP pairing (BLE management access), but lock/unlock uses the Unlock/Lock characteristic (Write Without Response, no SMP, no PIN). Guest users who only lock/unlock never need the PIN.

### Slot Tiers

| Slot | Tier | Default Name | PIN Knowledge | Management Access |
|---|---|---|---|---|
| 0 | Hardware | `Uguisu` | N/A | None (USB-only via Whimbrel/Android OTG) |
| 1 | Owner | *(set during onboarding)* | Yes | Full |
| 2 | Guest | `Guest 1` | No | None (lock/unlock only) |
| 3 | Guest | `Guest 2` | No | None (lock/unlock only) |

Tier is implicit from slot number — no additional metadata stored.

### The `IDENTIFY` Command

Guillemot can't determine which slot is connecting for management from SMP alone (SMP proves PIN knowledge, not slot identity). New command added:

- Phone sends a 14-byte AES-CCM payload (same format as lock/unlock) with command byte `0x02` through the Management Command characteristic
- Guillemot decrypts using the claimed slot's key — if MIC valid + counter valid, session is bound to that slot
- All subsequent management commands are gated by the identified tier

| Command | Owner | Guest | No IDENTIFY |
|---|---|---|---|
| `IDENTIFY` | ✓ | ✓ | N/A |
| `SLOTS?` | ✓ | ✓ | ✓ (read-only) |
| `PROV` | ✓ | ✗ | ✗ |
| `REVOKE` | ✓ | ✗ | ✗ |
| `RENAME` (own slot) | ✓ | ✓ | ✗ |
| `RENAME` (other slot) | ✓ | ✗ | ✗ |

### Guest Provisioning — Unencrypted QR

Guest QR codes are **plaintext** (no Argon2id, no PIN):
```
immogen://prov?slot=2&key=<hex>&ctr=0&name=Guest%201
```

vs owner/migration (encrypted):
```
immogen://prov?slot=1&salt=<hex>&ekey=<encrypted_key_hex>&ctr=0&name=iPhone
```

The scanning phone distinguishes by field presence (`key` = plaintext, `ekey` + `salt` = encrypted). Security trade-off accepted: intercepted guest QR exposes the slot key, but (a) exchange is in-person, (b) owner can revoke at any time, (c) guest key grants no management access.

---

## 6. Settings — Owner vs Guest

Two distinct settings panes rendered based on the stored slot ID.

### Owner Settings (Slot 1)

| Section | Contents |
|---|---|
| **Proximity** | Background Unlock toggle, Unlock Distance slider, Lock Distance slider (10 dBm hysteresis enforced) |
| **Keys** (inline) | All 4 slots with tier labels. Slot 0: ⋮ Replace via USB (Android). Slot 1: own slot, no ⋮. Guest slots: ⋮ Rename/Replace/Delete. Empty slots: ⊕ → Provision Guest flow |
| **Device** | Transfer to New Phone, Change PIN via USB (Android), Flash Firmware via USB (Android) |
| **About** | Version, debug info on tap-hold |

### Guest Settings (Slot 2–3)

| Section | Contents |
|---|---|
| **Proximity** | Same as owner (phone-local settings) |
| **Your Key** | Single row: own slot name + "Transfer to New Phone" |
| **About** | Version |

No key management, no slot list, no USB operations, no PIN access.

---

## 7. Key Management Flows

### Provision Guest Phone (from ⊕ on empty slot)
Confirm → keygen → `PROV:<slot>:<key>:0:Guest N` → plaintext QR display. No name prompt (defaults to "Guest 1"/"Guest 2"), no PIN. One-tap flow.

### Replace (from ⋮ on active slot)
Confirm revocation → `REVOKE` → keygen → `PROV` → QR (plaintext for guest, encrypted for owner). Default name restored. Self-Provisioning Variant for "recover key from lost phone" onboarding path: connects to Guillemot via SMP, picks slot to replace, provisions self (no QR).

### Migration / Transfer to New Phone
Confirm → PIN entry (owner) or skip (guest) → QR display → "Done — I've Scanned" → confirm key deletion → key wiped, app returns to onboarding. QR includes current counter value for seamless takeover.

### Change PIN (Android only, USB serial)
Connect Guillemot via USB OTG → enter + confirm new 6-digit PIN → `SETPIN` via CDC serial. Existing SMP bonds unaffected; new PIN only applies to future pairing.

### USB Flashing (Android only)
Guillemot: UF2 mass storage via `libaums`. Uguisu: CDC serial firmware + key flash via `usb-serial-for-android`. Slot 0 replace (from ⋮ in key management) also routes through USB OTG.

---

## 8. Changes to Core Architecture (Sections 2, 5, 6, 7 of Log 33)

The UI/UX session surfaced protocol-level changes that were written back into the master architecture:

- **Section 2:** Slot tier table added (Hardware / Owner / Guest)
- **Section 5.5 (new):** `IDENTIFY` command spec, permission matrix, rationale for why SMP bonds alone are insufficient
- **Section 6.1:** `IDENTIFY` added to command transport table with tier gate column
- **Section 7.1.1 (new):** Guest provisioning with unencrypted QR, format differentiation (`key` vs `ekey`+`salt`)

All changes are reflected in log 33 as the single source of truth.

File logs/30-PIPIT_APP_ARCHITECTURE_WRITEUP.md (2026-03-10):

# Pipit: Companion App Architecture & Technical Writeup

*Date: 2026-03-10*

**Status:** Architectural Blueprint & Rationale
**Scope:** Architecture for the "Pipit" companion iOS/Android app, cross-platform core, UI framework, BLE strategy, and key provisioning.

---

## 1. Executive Summary

**Pipit** is the companion iOS and Android application for the Immogen vehicle immobilizer ecosystem. Named to follow the ornithological theme (Guillemot, Uguisu, Whimbrel), Pipit serves two primary functions:

1. **Proximity Unlock (Background):** A low-power background service that detects when the user approaches the vehicle and automatically unlocks Guillemot, with an adjustable proximity threshold.
2. **Active Key Fob (Foreground):** A user interface to manually lock and unlock the vehicle, functioning identically to the Uguisu hardware fob.

To balance cross-platform efficiency with platform-native performance, Pipit uses **Kotlin Multiplatform (KMP)** for shared business logic while maintaining strictly native UI frameworks (**SwiftUI/UIKit** for iOS, **Jetpack Compose** for Android).

---

## 2. Core Architecture Decisions & Rationale

### 2.1 Cross-Platform Core: Kotlin Multiplatform (KMP)
Rather than writing the business logic twice (Swift for iOS, Kotlin for Android) or wrapping the existing C++ firmware codebase (`immo_crypto.cpp`) in JNI/Objective-C++, we elected to use **Kotlin Multiplatform**.

**Rationale:**
* **Developer Experience:** Native Kotlin development provides zero friction on Android and compiles to a highly performant, Swift-friendly native framework for iOS.
* **Memory Safety:** KMP offers a modern, memory-safe environment compared to maintaining manual memory management via C++ wrappers.
* **Trade-off:** The primary trade-off is the need to port the existing C++ AES-CCM (RFC3610) cryptography and MAC logic into pure Kotlin. To mitigate risks, this KMP implementation will be exhaustively unit-tested against the existing C++ test vectors to guarantee bit-for-bit parity.

### 2.2 User Interface: Platform-Native (Compose & SwiftUI)
The application will not use cross-platform UI frameworks like Flutter or React Native.

**Rationale:**
* **Native Feel:** The app must feel like a first-class citizen on both platforms. 
* **Hardware Integration:** BLE interactions, camera usage (for QR scanning), and secure enclave access are deeply intertwined with the UI/UX. Relying on native toolkits—**Jetpack Compose** for Android and **SwiftUI/UIKit** for iOS—ensures smooth, reliable integrations with platform-specific APIs.

### 2.3 Provisioning Strategy: QR Code & Secure Enclave
To provision a phone as a trusted key, Pipit will use the device's camera to scan a QR code displayed by **Whimbrel** (during initial setup) or by **another Pipit instance** (for subsequent phones, post-installation).

The QR code encodes a provisioning URI containing the slot key and a 6-digit management PIN: `immogen://prov?slot=<n>&key=<hex>&ctr=0&pin=<6digits>`. The management PIN enables BLE-authenticated key slot management after installation (see Integration Requirements doc §1.3).

**Rationale:**
* **Security & Usability:** QR codes provide a high-bandwidth, air-gapped method of securely transferring root cryptographic keys without pairing over a vulnerable, unencrypted BLE channel.
* **Storage:** Once scanned, the slot key is stored strictly within the device's hardware-backed keystores: **Android Keystore** and **iOS Keychain**. The management PIN is stored alongside it. These secrets never touch plaintext storage, ensuring the app remains secure even if the host OS is compromised.
* **Pipit as Provisioning Client:** A provisioned Pipit instance can authenticate to Guillemot over BLE using the management PIN and perform key management post-installation — provisioning additional phones (displaying QR codes), revoking lost devices, and changing the management PIN. On **Android**, Pipit additionally supports USB operations via OTG: firmware flashing (UF2 mass storage via `libaums`) and Uguisu fob provisioning (CDC serial via `usb-serial-for-android`). On **iOS**, USB operations are not available (no USB device API); these require Whimbrel on a laptop. See the Integration Requirements doc §4 for the full platform capability matrix.

---

## 3. Background BLE Architecture (The iOS Challenge)

The most complex requirement is ensuring reliable background proximity unlock, particularly on iOS. 

### 3.1 The iOS Background Advertising Limitation
Initially, the intuitive approach is to have the phone act as a BLE Peripheral (Broadcaster) continuously announcing its presence, and Guillemot acting as the Central (Scanner) to detect the phone. 

However, **iOS severely restricts background BLE advertising.** When an iOS app goes into the background, Apple strips out the Manufacturer Data and hashes the custom Service UUID into an undocumented, proprietary "overflow area." Since Guillemot runs on an nRF52840 MCU and not Apple silicon, it cannot easily decode this proprietary hash to recognize the iPhone.

### 3.2 The Flipped Solution: Guillemot as Advertiser
To achieve 100% reliable background wake-ups on both iOS and Android, the architecture flips the traditional BLE roles:

1. **Guillemot acts as a Central AND a Peripheral:**
   * It continues its 5% duty-cycle scanning (25ms window / 500ms interval) to listen for Uguisu fobs.
   * *Simultaneously*, it broadcasts a slow, continuous advertisement beacon containing a specific "Immogen Proximity" Service UUID every **500ms**.
2. **Pipit acts as the Central (Scanner):**
   * The Pipit app registers a background scanner with the OS (via CoreBluetooth on iOS and `BluetoothLeScanner` with a Foreground Service on Android) specifically looking for the "Immogen Proximity" Service UUID.
   * When the user walks within range, the phone's OS hardware detects the 500ms beacon and wakes the Pipit app in the background. **Note:** iOS background scan delivery is not instantaneous—CoreBluetooth may batch scan results and deliver them with a delay ranging from sub-second to several minutes, depending on iOS version, device state, and app usage recency. `CBCentralManagerScanOptionAllowDuplicatesKey` is also ignored in background mode. The implementation must use `centralManager:willRestoreState:` for state restoration to maximize reliability.
   * Pipit connects to Guillemot, executes the challenge-response authentication, and unlocks the vehicle.

### 3.3 Power Consumption Impact on Guillemot
One concern with Guillemot advertising continuously is battery drain. However, the math proves this impact is negligible:
* **Current Scan Draw:** ~306 µA (5% duty cycle listening for Uguisu).
* **New Beacon Draw:** Advertising once every 500ms requires ~2ms of TX active time at ~5.3 mA, which averages to just **~21.2 µA**.
* **Total New Power Draw:** ~327 µA.
* **Battery Life Effect:** At 327 µA, a 15.3 Ah scooter battery will last roughly 5.3 years in standby mode, which is far beyond the natural self-discharge rate of lithium-ion cells (~12 months).

**Rationale:** Trading ~21 µA of power on Guillemot for 100% reliable iOS background wake-ups is an optimal architectural compromise.

### 3.4 End-to-End Unlock Latency (GATT Path)
Unlike Uguisu's connectionless broadcast (which Guillemot detects in a single scan window), the Pipit unlock path involves multiple sequential BLE operations after the background wake-up:

| Step | Typical Latency |
|---|---|
| iOS/Android background scan delivery | Sub-second to minutes (variable; see §3.2 note) |
| GATT connection establishment | ~50–200 ms |
| Service & characteristic discovery | ~100–300 ms |
| Encrypted payload write + ACK | ~10–50 ms |
| Guillemot `verify_payload()` + latch actuation | ~5–15 ms |
| **Total (post-wake)** | **~165–565 ms** |

In practice, the post-wake GATT path will feel near-instant once the phone has been woken. The dominant latency variable is the OS background scan delivery itself. Users should expect that proximity unlock via Pipit will not feel as instantaneous as a physical Uguisu fob press, particularly on iOS where background scan batching can introduce noticeable delay.

---

## 4. Implementation Blueprint

To realize this architecture, the implementation will be split into the following phases:

1. **KMP Project Scaffolding:** Create the Pipit monorepo structure containing `shared`, `androidApp`, and `iosApp`.
2. **Crypto & Protocol Porting:** Implement pure-Kotlin versions of `immo_crypto.cpp` (AES-128 and RFC3610 MIC generation) inside the KMP `shared` module, validating against established test vectors.
3. **Platform Interfaces (expect/actual):** Define KMP wrappers for secure storage (Keychain/Keystore) and BLE Central managers.
4. **Guillemot Firmware Update:** Modify `Guillemot/firmware/src/main.cpp` and `guillemot_nrf52840.h` to emit the 500ms advertisement beacon.
5. **Native UI & Hardware Integration:** Build the QR scanning provisioning flow and the foreground Key Fob interfaces using Jetpack Compose and SwiftUI.
6. **Background Services:** Implement Android Foreground Services and iOS CoreBluetooth background modes to handle the proximity wake-up and automated authentication sequence.

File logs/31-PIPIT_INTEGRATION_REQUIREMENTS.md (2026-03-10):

# Pipit App Integration: Architecture & Technical Requirements

*Date: 2026-03-10*

**Status:** Technical Writeup
**Scope:** Outline of required changes and key architectural decisions for Immogen (Guillemot) and Whimbrel to support the new Pipit companion app.

---

## 1. Key Architectural Decisions

### 1.1 Multi-Device Counter & Key Management (CRITICAL)
Currently, Guillemot only stores a single 16-byte Pre-Shared Key (`g_psk`) and tracks a single monotonically increasing counter to prevent replay attacks.
* **The Problem:** If the Uguisu physical fob and the Pipit app share the *same* key and counter, they will desync. Unlocking via Pipit would advance Guillemot's counter, leaving Uguisu's internal counter lagging behind. Subsequent fob presses would be rejected until Uguisu "catches up."
* **The Decision:** Guillemot must be updated to support a fixed array of **4 Key Slots** (Slot 0–3), each with independent PSK and counter storage. Slot 0 is reserved for the Uguisu hardware fob; Slots 1–3 are available for Pipit companion app instances. When all slots are occupied, a new device cannot be provisioned until an existing slot is revoked (see §1.3).

### 1.2 GATT Protocol Design vs. Connectionless Broadcasting
The Uguisu fob operates connectionlessly: it broadcasts its unlock payload (as a Peripheral) and Guillemot scans for it (as a Central). For Pipit, however, a GATT connection is strictly required due to mobile OS constraints and the direction of data flow.

* **The Directional Constraint:** Guillemot controls the physical vehicle latch, meaning the unlock command *must* ultimately flow from Pipit to Guillemot.
* **Why Connectionless Fails:** To replicate Uguisu's flow, Pipit would need to broadcast the payload in the background. However, iOS severely restricts background BLE advertising—CoreBluetooth automatically strips out custom Manufacturer Specific Data and hashes Service UUIDs into an Apple-proprietary format. If Pipit broadcasted in the background, Guillemot would scan empty packets and never receive the unlock command.
* **The "Flipped" Discovery:** To guarantee reliable background wake-ups, the roles must be flipped for discovery: Guillemot acts as the Advertiser (emitting a 500ms beacon) and Pipit acts as the Scanner.
* **The GATT Requirement:** Once Guillemot's beacon wakes Pipit up, Pipit still holds the unlock payload. Because the BLE specification does not allow a Scanner to send custom data connectionlessly (e.g., inside a Scan Request), Pipit is forced to establish a GATT connection with the Advertiser to write the data.
* **The Decision:** Guillemot must host a GATT Server. The simplest migration path is to expose a single `Command` characteristic. Pipit will connect and write an encrypted AES-CCM payload (identical in format to Uguisu's MSD), which Guillemot will then route through its existing `verify_payload()` logic.

### 1.3 Management PIN & BLE Key Management
Once Guillemot is installed inside the vehicle, requiring USB-C serial access for routine key management (revoking a lost phone, adding a replacement) would mean a full vehicle teardown. To avoid this, key slot management is exposed over BLE, authenticated by a **6-digit management PIN**.

#### 1.3.1 Provisioning Lifecycle (Whimbrel Onboarding Flow)
The Whimbrel dashboard guides the user through the following steps in order:

1. **Flash Guillemot firmware** via USB-C DFU. *(Skippable — a "Skip" button is provided for devices with firmware already flashed.)*
2. **Provision Uguisu** (Slot 0 fob key). Whimbrel generates a key, flashes it to the Uguisu fob via USB-C serial, and prompts the user to disconnect Uguisu.
3. **Provision Guillemot** (Slot 0). Whimbrel flashes the same key to Guillemot via USB-C serial (`PROV:0:<key>:<counter>`). No management PIN is set at this stage — fob-only users manage slots exclusively via wired connection.
4. **"Add a phone key?"** prompt. If the user declines, onboarding is complete.
5. **"Enter a management PIN"** prompt. The user enters a new 6-digit PIN. Whimbrel sends the PIN hash to Guillemot via serial (`SETPIN:<hash>`) and provisions a new key into Slot 1 (`PROV:1:<key>:<counter>`).
6. **QR code display.** Whimbrel encodes the slot key and management PIN into a QR code (`immogen://prov?slot=1&key=<hex>&ctr=0&pin=<6digits>`) and displays it with obscure/reveal controls for the phone to scan.

**Post-installation provisioning:** Subsequent phones (Slots 2–3) and replacement Uguisu fobs can be provisioned without USB-C access to Guillemot. The user authenticates to Guillemot over BLE using the management PIN (via Whimbrel over Web Bluetooth, or via Pipit) and provisions new slot keys. For phone slots, a QR code is displayed for the target phone to scan. For Uguisu fob replacement, Pipit on Android connects to the fob directly via USB-C OTG to flash the new key. iOS does not support USB serial communication, so fob provisioning from an iPhone requires Whimbrel on a laptop (see §4 Platform Capability Matrix).
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

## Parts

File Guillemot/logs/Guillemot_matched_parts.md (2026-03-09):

# Guillemot BOM - Matched Parts

## Matched Components

| Designator  | Comment | Footprint | Part Name | LCSC | Description / Specs | Qty | Type | Total Cost |
| --- | --- | --- | --- | --- | --- | --- | --- | --- |
| BZ1 | FUET-1230 | BUZ-SMD_L12.0-W12.0_FUET-1230 | FUET-1230 | C391037 | -20℃~~+70℃ 12mm 12mm 1V~~25V 3.3mm 3V 4kHz 5mA 75dB Passive (Externally Driven) Piezoelectric SMD,12x12mm Buzzers ROHS | 5 | Extended | $2.3640 |
| C1 | 10nF | 0603 | 0603B103K500NT | C57112 | 10nF 50V X7R ±10% 0603 Multilayer Ceramic Capacitors MLCC - SMD/SMT ROHS | 5 | Basic | $0.0140 |
| C2 | 100µF | 1210 | EMK325ABJ107MM-P | C90143 | 100uF 16V X5R ±20% 1210 Multilayer Ceramic Capacitors MLCC - SMD/SMT ROHS | 5 | Extended | $1.5285 |
| C3,C4 | 1uF | 0603 | CL10A105KB8NNNC | C15849 | 1uF 50V X5R ±10% 0603 Multilayer Ceramic Capacitors MLCC - SMD/SMT ROHS | 5 | Basic | $0.0720 |
| D1 | BZT52C12-7-F | D_SOD-123 | BZT52C12-7-F | C124196 | -65℃~~+150℃ 100nA@1V 11.4V~~12.7V 12V 150Ω 25Ω 370mW Independent SOD-123 Zener Diodes ROHS | 5 | Extended | $0.5538 |
| D2 | BZT52C10-7-F | D_SOD-123 | BZT52C10-7-F | C155227 | -65℃~~+150℃ 10V 150Ω 200nA 20Ω 370mW 9.4V~~10.6V Independent SOD-123 Zener Diodes ROHS | 5 | Extended | $0.5085 |
| D3,D4 | 1N4148W | D_SOD-123 | 1N4148W | C81598 | 1.25V@150mA 100V 150mA 1uA@75V 2A 4ns 500mW Independent SOD-123 Switching Diodes ROHS | 10  | Basic | $0.1100 |
| D5 | SMBJ45A | D_SMB | SMBJ45A | C114005 | -65℃~+150℃ 1uA 45V 55.3V 600W@10/1000us 72.7V 8.3A@10/1000us TVS Unidirectional DO-214AA(SMB) ESD and Surge Protection | 5 | Extended | $0.4221 |
| PS1 | TPSM365R6V3RDNR | CONV_TPSM365R6V3RDNR | TPSM365R6V3RDNR | C18208843 | -40℃~~+125℃ 1MHz 2mm 3.3V 3.5mm 3.6V~~65V 4.5mm 4uA 600mA 80.2% Buck Overheat protection、Over Current Protection ±1.5% | 5 | Extended | $17.9375 |
| Q1 | IPB042N10N3G | TO-263-2 | IPB042N10N3G | C69300 | -55℃~+175℃ 1 N-channel 100V 117nC 137A 214W 3.5V 4.2mΩ@10V 41pF 8.41nF TO-263-3 MOSFETs ROHS | 5 | Extended | $3.7630 |
| Q2 | AO3422 | SOT-23 | AO3422 | C37130 | 1 N-channel 10A 12.6pF 160mΩ@4.5V 2V [3.3nC@4.5V](mailto:3.3nC@4.5V) 300pF 55V N-Channel SOT-23 MOSFETs ROHS | 5 | Extended | $1.1376 |
| Q3 | SI2309CDS | SOT-23 | SI2309CDS-T1-GE3 | C10493 | -55℃~+150℃ 1 P-Channel 1.6A 1.7W 20pF 210pF 28pF 3V [4.1nC@4.5V](mailto:4.1nC@4.5V) 450mΩ@4.5V 60V P-Channel SOT-23-3 MOSFETs ROHS | 5 | Extended | $1.1333 |
| Q4 | 2N7002 | SOT-23 | 2N7002 | C8545 | 1 N-channel 115mA 2.5V 225mW 50pF 5pF 5Ω@10V 60V SOT-23 MOSFETs ROHS | 5 | Basic | $0.0660 |
| Q5,Q6 | MMBT3904 | SOT-23 | MMBT3904(RANGE:100-300) | C20526 | -55℃~+150℃ 1 NPN 100 100nA 200mA 200mW 300MHz 300mV 40V 6V NPN SOT-23 Bipolar (BJT) ROHS | 5 | Basic | $0.0950 |
| R1,R2,R3,R7 | 100k | 0603 | 0603WAF1003T5E | C25803 | -55℃~+155℃ 100kΩ 100mW 75V Thick Film Resistor ±1% ±100ppm/℃ 0603 Chip Resistor - Surface Mount ROHS | 5 | Basic | $0.0280 |
| R4 | 1M | 0603 | 0603WAF1004T5E | C22935 | -55℃~+155℃ 100mW 1MΩ 75V Thick Film Resistor ±1% ±100ppm/℃ 0603 Chip Resistor - Surface Mount ROHS | 5 | Basic | $0.0065 |
| R5 | 10k | 0603 | 0603WAF1002T5E | C25804 | -55℃~+155℃ 100mW 10kΩ 75V Thick Film Resistor ±1% ±100ppm/℃ 0603 Chip Resistor - Surface Mount ROHS | 5 | Basic | $0.0065 |
| R6 | 4.7k | 0603 | 0603WAF4701T5E | C23162 | -55℃~+155℃ 100mW 4.7kΩ 75V Thick Film Resistor ±1% ±100ppm/℃ 0603 Chip Resistor - Surface Mount ROHS | 5 | Basic | $0.0065 |
| R8 | 472W | 2512 | RC2512JK-7W47RL | C136992 | -55℃~+155℃ 200V 2W 47Ω Thick Film Resistor ±200ppm/℃ ±5% 2512 Chip Resistor - Surface Mount ROHS | 5 | Extended | $0.5184 |
| U2 | SN74LVC2G02DCTR | MSOP-8_L2.9-W2.8-P0.65-LS4.0-BR | SN74LVC2G02DCTR | C94600 | -40℃~~+125℃ 1.2V、1.9V、2.3V、2.4V、3.8V 1.65V~~5.5V 1.7V~2V 10uA 2 2 300mV、400mV、450mV、550mV 32mA 32mA 4.4ns@5V,50pF 74LVC | 5 | Extended | $2.6565 |

## Unmatched Components

| Designator | Comment |
| --- | --- |
| U1 | XIAO-nRF52840-SMD |

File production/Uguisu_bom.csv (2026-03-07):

Designator | Footprint | Quantity | Value | LCSC Part #
KEY1 | KEY-SMD_4P-L5.2-W5.2-P3.70-LS6.4 | 1 | SKQGABE010 | C115351
LED1 | LED-ARRAY-SMD_6P-L5.0-W5.0-TL-RD_3 | 1 | XL-5050RGBC | C2843868
R1, R3 | 0603 | 2 | 120
R2 | 0603 | 1 | 330
TP1 | TestPoint_Pad_3.0x3.0mm | 1 | +BATT
TP2 | TestPoint_Pad_3.0x3.0mm | 1 | GND
U1 | XIAO-nRF52840-SMD | 1 | XIAO-nRF52840-SMD

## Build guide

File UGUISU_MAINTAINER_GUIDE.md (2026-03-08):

# Uguisu Maintainer Guide: Resolving the `File` Naming Collision

## Background

Both the `Adafruit_LittleFS` library and `SdFat` library (which is included automatically by the `Adafruit TinyUSB Library` for Mass Storage support) declare a `File` class in the global C++ namespace. When building a project that uses LittleFS on the Adafruit nRF52 core with TinyUSB, this causes a fatal naming collision.

Historically, this issue was sidestepped by using a fragile Python script (`extra_script.py`) to intercept the framework compilation and inject a custom header to hide `SdFat`. 

However, this method is brittle and prone to breaking when PlatformIO or the underlying framework updates.

## The Solution

A much cleaner, native solution is to use TinyUSB's built-in configuration macros to completely disable Mass Storage Class (MSC) support, which prevents the framework from including `SdFat` in the first place.

This fix has now been integrated directly into the shared `ImmoCommon` library.

## How to Update Uguisu

To apply this cleaner fix to the Uguisu fob project, you need to update its `platformio.ini` to consume the new shared configuration file.

### 1. Ensure `ImmoCommon` is Updated
First, make sure the `ImmoCommon` submodule in your Uguisu repository is pulled to the latest commit containing `src/immo_tusb_config.h`.

### 2. Update `platformio.ini`
In the Uguisu `platformio.ini` file, perform the following modifications:

1. **Remove the extra script hack:**
   Delete the line that says `extra_scripts = pre:extra_script.py`. You can also safely delete the `extra_script.py` file and the `include_fix` directory from the repository.

2. **Add the SPI library dependency:**
   Because TinyUSB was implicitly resolving the `SPI.h` dependency for the build graph, disabling MSC can cause PlatformIO's Library Dependency Finder (LDF) to miss it. Add `SPI` explicitly to `lib_deps`.

3. **Configure LDF to search deeper:**
   Add `lib_ldf_mode = deep+` to ensure PlatformIO correctly parses dependencies inside the modified framework macros.

4. **Add the Build Flags:**
   Inject the new configuration file via `-D CFG_TUSB_CONFIG_FILE`. You must also explicitly add the `ImmoCommon/src` directory to the global include path so that the TinyUSB library can find it during compilation.

### Example `platformio.ini` Changes:

```ini
; ... existing config ...

lib_deps =
  afantor/Bluefruit52_Arduino
  adafruit/Adafruit TinyUSB Library
  SPI            ; <-- Add this

lib_ldf_mode = deep+   ; <-- Add this

build_flags =
  ; ... other flags ...
  -D CFG_TUSB_CONFIG_FILE=\"immo_tusb_config.h\"   ; <-- Add this
  -I lib/ImmoCommon/src                            ; <-- Add this
  -I ".pio/libdeps/your_board_name/Adafruit TinyUSB Library/src"
```

Once these changes are made, the project will compile cleanly without the need for brittle python build scripts, and the `File` class will unambiguously resolve to `Adafruit_LittleFS`.

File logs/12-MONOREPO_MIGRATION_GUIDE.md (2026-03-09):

# Immogen Monorepo Migration Guide

**Last modified: 2026-03-09 23:28**

This guide describes how to merge Guillemot and Uguisu into the ImmoCommon repository, rename it to **Immogen**, and reconfigure releases. **Full git history is preserved** for all projects.

## Summary of changes

| Item | Before | After |
|---|---|---|
| Repo name | ImmoCommon | **Immogen** |
| Releases | Separate per project | **Single release** with both firmwares |
| Release artifacts | firmware.zip, firmware.hex per repo | guillemot-1.0.0.zip, guillemot-1.0.0.hex, uguisu-1.0.0.zip, uguisu-1.0.0.hex |
| Internal code | immo::, ImmoCommon.h | **Unchanged** (Option A) |

---

## Prerequisites

- Git 2.23+ (for `git subtree`)
- Clean working tree in all three repos
- Push any pending commits before starting
- **Back up** your work

---

## Target Layout

Use **uppercase** `Guillemot` and `Uguisu`; flatten firmware paths to `/Guillemot/firmware` and `/Uguisu/firmware` (no extra `guillemot/` or `uguisu/` subfolder).

```
Immogen/                              # single repo (renamed from ImmoCommon)
├── lib/                              # shared library (current ImmoCommon src)
│   ├── src/
│   │   ├── immo_crypto.cpp
│   │   ├── immo_provisioning.cpp
│   │   └── ...
│   └── tools/
├── Guillemot/                        # receiver (from Guillemot repo)
│   ├── firmware/                     # platformio project directly here
│   ├── *.kicad_*
│   └── ...
├── Uguisu/                           # fob (from Uguisu repo)
│   ├── firmware/                     # platformio project directly here
│   ├── *.kicad_*
│   └── ...
├── tools/                            # consolidated HTML tools from both projects
│   ├── led_visualizer.html            # from Uguisu
│   ├── ble_timing_simulator.html      # from Uguisu
│   └── buzzer_tuner.html              # from Guillemot
└── .github/
    └── workflows/
        └── release.yml
```

---

## Phase 1: Prepare ImmoCommon (pre-rename)

Work in a **fresh clone** to avoid touching your main workspace.

```bash
cd /tmp
git clone https://github.com/LPFchan/ImmoCommon.git immogen-monorepo
cd immogen-monorepo
```

### 1.1 Restructure: move src and tools into lib/

```bash
mkdir -p lib
git mv src lib/
git mv tools lib/ 2>/dev/null || true
git add -A
git commit -m "Restructure: move src and tools into lib/ for monorepo layout"
```

---

## Phase 2: Add Guillemot with History

### 2.1 Add Guillemot subtree

```bash
git subtree add --prefix=Guillemot https://github.com/LPFchan/Guillemot.git main
```

### 2.2 Flatten firmware directory

```bash
mv Guillemot/firmware/guillemot/* Guillemot/firmware/
rm -rf Guillemot/firmware/guillemot
```

### 2.3 Remove Guillemot's ImmoCommon submodule

```bash
rm -rf Guillemot/firmware/lib/ImmoCommon
```

Delete `Guillemot/.gitmodules` (or remove the ImmoCommon entry) so the integrated tree doesn't appear as a submodule:

```bash
rm -f Guillemot/.gitmodules
```

### 2.4 Update Guillemot platformio.ini

Edit `Guillemot/firmware/platformio.ini`:

**Change:** Replace `-I lib/ImmoCommon/src` with `-I ../../lib/src`

### 2.5 Commit

```bash
git add Guillemot/
git commit -m "Integrate Guillemot: flatten firmware, remove lib submodule, point to in-tree lib"
```

---

## Phase 3: Add Uguisu with History

### 3.1 Add Uguisu subtree

```bash
git subtree add --prefix=Uguisu https://github.com/LPFchan/Uguisu.git main
```

### 3.2 Flatten firmware directory

```bash
mv Uguisu/firmware/uguisu/* Uguisu/firmware/
rm -rf Uguisu/firmware/uguisu
```

### 3.3 Remove Uguisu's ImmoCommon submodule

```bash
rm -rf Uguisu/firmware/lib/ImmoCommon
```

Delete `Uguisu/.gitmodules` (or remove the ImmoCommon entry):

```bash
rm -f Uguisu/.gitmodules
```

### 3.4 Update Uguisu platformio.ini

Edit `Uguisu/firmware/platformio.ini`:

**Change:** Replace `-I lib/ImmoCommon/src` with `-I ../../lib/src`

### 3.5 Consolidate tools to repo root

Move the three HTML tools to the new `tools/` directory at repo root:

```bash
mkdir -p tools
mv Uguisu/tools/led_visualizer.html tools/
mv Uguisu/tools/ble_timing_simulator.html tools/
mv Guillemot/tools/buzzer_tuner.html tools/
```

### 3.6 Commit

```bash
git add Uguisu/ Guillemot/ tools/
git commit -m "Integrate Uguisu: flatten firmware, remove submodule, consolidate tools to /tools"
```

---

## Phase 4: Single Release Workflow (Both Firmwares)

One tag (e.g. `v1.0.0`) builds **both** Guillemot and Uguisu and creates a single release with four artifacts:
- `guillemot-1.0.0.hex`
- `guillemot-1.0.0.zip`
- `uguisu-1.0.0.hex`
- `uguisu-1.0.0.zip`

### 4.1 Create `.github/workflows/release.yml`

```yaml
name: Release

permissions:
  contents: write

on:
  push:
    tags:
      - 'v*'

jobs:
  build-and-release:
    runs-on: ubuntu-latest
    steps:
      - name: Checkout
        uses: actions/checkout@v4

      - name: Set up Python
        uses: actions/setup-python@v5
        with:
          python-version: '3.11'

      - name: Install PlatformIO
        run: pip install -U platformio

      - name: Build Guillemot
        working-directory: Guillemot/firmware
        run: pio run

      - name: Build Uguisu
        working-directory: Uguisu/firmware
        run: pio run

      - name: Rename artifacts for release
        run: |
          V=${GITHUB_REF#refs/tags/v}
          cp Guillemot/firmware/.pio/build/seeed_xiao_nrf52840_bluefruit/firmware.hex guillemot-${V}.hex
          cp Guillemot/firmware/.pio/build/seeed_xiao_nrf52840_bluefruit/firmware.zip guillemot-${V}.zip
          cp Uguisu/firmware/.pio/build/seeed_xiao_nrf52840_bluefruit/firmware.hex uguisu-${V}.hex
          cp Uguisu/firmware/.pio/build/seeed_xiao_nrf52840_bluefruit/firmware.zip uguisu-${V}.zip

      - name: Create release
        uses: softprops/action-gh-release@v2
        with:
          tag_name: ${{ github.ref_name }}
          name: ${{ github.ref_name }}
          files: |
            guillemot-*.hex
            guillemot-*.zip
            uguisu-*.hex
            uguisu-*.zip
        env:
          GITHUB_TOKEN: ${{ secrets.GITHUB_TOKEN }}
```

### 4.2 Remove old workflow files

Delete any release workflows inside Guillemot and Uguisu; the single workflow at repo root replaces them.

---

## Phase 5: Rename ImmoCommon → Immogen

### 5.1 Rename GitHub repository

1. Go to **ImmoCommon** → **Settings** → **General**
2. Under "Repository name", change `ImmoCommon` to **Immogen**
3. Click **Rename**

### 5.2 Update local clone remote

```bash
git remote set-url origin https://github.com/LPFchan/Immogen.git
```

### 5.3 Update README and docs

- Replace "ImmoCommon" with "Immogen" in:
  - `README.md` (root)
  - `lib/` README if present
  - Any `Guillemot/` or `Uguisu/` docs that reference the repo
- Update GitHub URLs to `LPFchan/Immogen`
- Optionally add a note: "Immogen (formerly ImmoCommon) — shared library for the BLE immobilizer system"

### 5.4 Commit and push

```bash
git add README.md
git add -A
git commit -m "Rename project to Immogen"
git push origin main
```

---

## Phase 6: Update Whimbrel

Whimbrel fetches releases from GitHub. After migration, use the **Immogen** repo and expect one release with four assets.

### 6.1 Update release API base

In `Whimbrel/js/api.js` (or equivalent), change:

- From: separate fetch to `LPFchan/Guillemot` and `LPFchan/Uguisu`
- To: single fetch to `LPFchan/Immogen`

The existing filter `r.assets.some((a) => a.name.endsWith(".zip"))` still works, since each release will have multiple `.zip` assets.

### 6.2 Update asset selection

Releases now contain both device types per release:
- `guillemot-{version}.zip` and `guillemot-{version}.hex`
- `uguisu-{version}.zip` and `uguisu-{version}.hex`

**Important:** The current `releaseData.assets.find((a) => a.name.endsWith(".zip"))` returns the first `.zip` asset, which may not match the selected device. Update logic to:

1. Fetch the latest release from Immogen (once per device selection).
2. Filter assets by device type: fob → `uguisu-*.zip`, receiver → `guillemot-*.zip`.

Example:

```javascript
const prefix = fwSelectedDeviceName === "Guillemot" ? "guillemot" : "uguisu";
const zipAsset = releaseData.assets.find((a) => a.name.startsWith(prefix) && a.name.endsWith(".zip"));
```

### 6.3 Update config

In `Whimbrel/js/config.js`, add `GITHUB_REPO` and set it to `Immogen`:

```javascript
GITHUB_OWNER: "LPFchan",
GITHUB_REPO: "Immogen",
```

Update `fetchReleases` / `fetchDeviceReleases` to use `CONFIG.GITHUB_REPO` instead of hardcoded `"Guillemot"` or `"Uguisu"` when fetching from Immogen.

---

## Phase 7: Verify and Push

### 7.1 Build both firmwares locally

```bash
cd Guillemot/firmware
pio run
cd ../..

cd Uguisu/firmware
pio run
cd ../..
```

### 7.2 Verify history

```bash
git log --oneline -20
git log --oneline Guillemot/
git log --oneline Uguisu/
```

### 7.3 Push to remote

```bash
git push origin main
```

---

## Phase 8: Post-Migration Cleanup

1. **Archive Guillemot and Uguisu repos**
   - Settings → Danger Zone → Archive repository
   - Add README notice: "Merged into [Immogen](https://github.com/LPFchan/Immogen)."

2. **Update external links**
   - Docs, badges, or references to ImmoCommon or old repo URLs

3. **Release workflow setup**
   - Ensure `RELEASE_TOKEN` (or equivalent) secret exists if required for releases

---

## Release usage

After migration, tag and push to trigger a release:

```bash
git tag v1.0.0
git push origin v1.0.0
```

This builds both firmwares and creates a release with:
- `guillemot-1.0.0.hex`
- `guillemot-1.0.0.zip`
- `uguisu-1.0.0.hex`
- `uguisu-1.0.0.zip`

---

## Checklist

- [x] Phase 1: Restructure ImmoCommon (src → lib/)
- [x] Phase 2: subtree add Guillemot, flatten firmware, remove submodule, fix platformio.ini, delete .gitmodules
- [x] Phase 3: subtree add Uguisu, flatten firmware, remove submodule, consolidate tools to /tools, fix platformio.ini, delete .gitmodules
- [x] Phase 4: Single CI workflow (both firmwares, renamed artifacts)
- [x] Phase 5: Rename repo to Immogen, update docs
- [x] Phase 6: Update Whimbrel (Immogen, GITHUB_REPO, asset selection by device type)
- [ ] Phase 7: Build both, verify history, push
- [ ] Phase 8: Archive old repos, update links

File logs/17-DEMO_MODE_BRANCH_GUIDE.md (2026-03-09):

# Whimbrel: Syncing Main → Demo

**Last modified: 2026-03-10 01:53**

Documents how to bring `main` changes into the `demo` branch and re-enable demo flags.

---

## What Demo Mode Does

The `demo` branch runs without real hardware. All serial port operations, provisioning handshakes, and firmware flashing are simulated with timed delays. The UI and flow are otherwise identical to `main`.

Demo mode is activated by `window.WHIMBREL_DEMO = true` in `index.html`, which is read by `config.js` on load.

---

## Step 1: Merge Main

```bash
git checkout demo
git merge -X theirs main --no-edit
```

`-X theirs` accepts main's version for any conflicts, since main is the authoritative source. Demo flags are re-applied on top afterward.

### Verify the CSS was not corrupted

This is not optional. `-X theirs` has silently dropped CSS rules in a previous Whimbrel merge (March 2026): the `.release-item` and `.progress-container` blocks were replaced by a lone `.release-separator` from demo's side of the conflict. The page loaded fine but the firmware dropdown items were unstyled.

```bash
git diff main -- css/style.css
```

The only differences should be the `.demo-badge` block. If anything else is missing from main's side, restore it manually before proceeding.

---

## Step 2: Re-Apply Demo Flags

### `index.html`

Two changes:

1. Add `window.WHIMBREL_DEMO = true` **before** `config.js` loads:
```html
<script>window.WHIMBREL_DEMO = true;</script>
<script src="js/config.js"></script>
```

2. Add the demo badge to the tagline:
```html
<p class="tagline">Companion Web App for <a href="..." target="_blank">Immogen</a> (Guillemot + Uguisu) <span class="demo-badge" id="demo-badge" aria-hidden="true">Demo</span></p>
```

### `js/config.js`

Add `DEMO_MODE` immediately after the namespace declaration, before `CONFIG`:

```javascript
window.Whimbrel = window.Whimbrel || {};
window.Whimbrel.DEMO_MODE = typeof window !== "undefined" && window.WHIMBREL_DEMO === true;

window.Whimbrel.CONFIG = { ... };
```

### `js/serial.js`

In `isSupported()`, short-circuit for demo so the "unsupported browser" warning doesn't appear:

```javascript
window.Whimbrel.isSupported = function() {
  if (window.Whimbrel.DEMO_MODE) return true;
  return "serial" in navigator;
};
```

### `js/api.js`

In `fetchDeviceReleases()`, return a fake release before making any network call. Both asset names must be present so either device tile works:

```javascript
window.Whimbrel.fetchDeviceReleases = async function(repoName) {
  if (window.Whimbrel.DEMO_MODE) {
    return [{ tag_name: "v0.1.0", html_url: "#", assets: [
      { name: "guillemot-v0.1.0.zip", browser_download_url: "#" },
      { name: "uguisu-v0.1.0.zip", browser_download_url: "#" }
    ]}];
  }
  // ... real implementation
};
```

The asset names must match the prefix filter in `firmware.js` (`guillemot-` or `uguisu-`). A mismatch causes the release selector to show no asset and leaves Flash disabled.

### `js/app.js`

Destructure `DEMO_MODE` at the top of the IIFE:

```javascript
const { CONFIG, DEMO_MODE, generateKey, ... } = window.Whimbrel;
```

In `provisionDevice()`, add the bypass immediately after setting `keysProvisioningInProgress = true`:

```javascript
if (DEMO_MODE) {
  try {
    setStatus("Writing key…");
    await abortableDelay(600, () => keysProvisionAborted);
    if (keysProvisionAborted) { setStatus(""); return; }
    setStatus("Waiting for device to boot…");
    await abortableDelay(900, () => keysProvisionAborted);
    if (keysProvisionAborted) { setStatus(""); return; }
    setStatus("Done. Device provisioned and running.");
    if (deviceId === CONFIG.DEVICE_ID_FOB) {
      fobFlashed = true;
      keysProvisioningInPostCircle = true;
      await runTimeout(el.timeoutIndicator, el.progressCircle, 1500, () => keysProvisionAborted);
      keysProvisioningInPostCircle = false;
      if (!keysProvisionAborted) showStep(2);
    }
    if (deviceId === CONFIG.DEVICE_ID_RX) receiverFlashed = true;
    if (fobFlashed && receiverFlashed && currentStepIdx === 2) {
      await showStep(3);
      triggerConfetti();
    }
  } catch (e) {
    if (!keysProvisionAborted) setStatus(e.message || "Demo error", true);
  } finally {
    keysProvisioningInProgress = false;
  }
  return;
}
// ... real implementation follows
```

### `js/firmware.js`

Destructure `DEMO_MODE` at the top:

```javascript
const { CONFIG, DEMO_MODE, fetchDeviceReleases, ... } = window.Whimbrel;
```

In the Flash button click handler, add the bypass immediately after `fwFlashAborted = false`:

```javascript
if (DEMO_MODE) {
  try {
    setFwStatus("Downloading firmware package...", 0);
    await abortableDelay(400, () => fwFlashAborted);
    if (fwFlashAborted) return;
    setFwStatus("Parsing zip file...", 0.1);
    await abortableDelay(300, () => fwFlashAborted);
    if (fwFlashAborted) return;
    setFwStatus("Starting DFU process...", 0.2);
    for (let i = 1; i <= 10; i++) {
      if (fwFlashAborted) return;
      setFwStatus("Writing firmware...", 0.2 + (i / 10) * 0.8);
      await abortableDelay(200, () => fwFlashAborted);
    }
    if (fwFlashAborted) return;
    setFwStatusSuccessWithLink();
    triggerConfetti();
  } catch (e) {
    if (!fwFlashAborted) setFwStatus(`Error: ${e.message}`, null, true);
  } finally {
    fwFlashingInProgress = false;
  }
  return;
}
// ... real implementation follows
```

### `css/style.css`

Add the `.demo-badge` block. In main this doesn't exist, so it belongs only in demo. Place it near the header/tagline styles:

```css
.demo-badge {
  display: inline-block;
  margin-left: 0.5rem;
  padding: 0.15rem 0.5rem;
  font-size: 0.75rem;
  font-weight: 600;
  text-transform: uppercase;
  letter-spacing: 0.05em;
  color: var(--surface);
  background: var(--success);
  border-radius: 4px;
  vertical-align: middle;
}
```

---

## Step 3: Commit and Push

```bash
git add index.html js/config.js js/serial.js js/api.js js/app.js js/firmware.js css/style.css
git commit -m "Sync main into demo and re-enable demo flags"
git push origin demo
```

If a CSS fix was needed after the merge, commit that separately with a clear message explaining what was restored and why.

---

## Checklist

- [ ] `git checkout demo && git merge -X theirs main --no-edit`
- [ ] `git diff main -- css/style.css` — verify no rules from main are missing
- [ ] `index.html`: `window.WHIMBREL_DEMO = true` before `config.js`; demo badge in tagline
- [ ] `config.js`: `DEMO_MODE` constant
- [ ] `serial.js`: `isSupported()` bypass
- [ ] `api.js`: fake release with both `guillemot-` and `uguisu-` zip assets
- [ ] `app.js`: `DEMO_MODE` destructured; `provisionDevice()` bypass
- [ ] `firmware.js`: `DEMO_MODE` destructured; Flash button bypass
- [ ] `css/style.css`: `.demo-badge` block present
- [ ] Open the firmware dropdown in browser — items should be left-aligned with padding and a separator above the custom options
- [ ] Full flow test: Guillemot → DFU instructions → Flash (should animate and confetti)
- [ ] Full flow test: Keys tab → Generate → Flash Fob → Flash Receiver → All done
- [ ] No Web Serial permission dialog should appear anywhere
- [ ] Commit and push

---

*Last updated: March 2026 (after monorepo sync + CSS corruption fix)*

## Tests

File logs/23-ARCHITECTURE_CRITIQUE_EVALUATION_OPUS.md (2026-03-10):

# Architecture Critique Evaluation

*Last modified: 2026-03-10*

Evaluation of every item from `21-ARCHITECTURE_CRITIQUE_COMBINED.md` against the actual codebase. Each item is rated: **Valid**, **Partially Valid**, **Wrong**, or **Misleading**.

---

## 1. LittleFS Power Drain — Valid, severity overstated

**Claimed problem:** On every button press, Uguisu linearly scans up to 512 CRC32-checked records from a 4KB LittleFS log just to read the last counter. Wastes milliseconds of CPU and flash power before BLE even starts.

**Evaluation:** Confirmed. `immo_storage.cpp:34-44` reads 8-byte records in a while loop. 4096 / 8 = 512 iterations max, each with `read()` + `crc32_ieee()`. However, CRC32 of 4 bytes is microseconds. The full scan is ~2-5ms total — not the power disaster described. The log only reaches 512 records after 512 button presses without rotation.

**Fix:** Add a `last_counter_` cache in a `.noinit` RAM section (survives `sd_power_system_off()`). On cold boot (battery insertion), scan LittleFS once and populate the cache. On subsequent wakes, read from RAM in microseconds.

```cpp
// In immo_storage.h — add retention cache
static uint32_t __attribute__((section(".noinit"))) s_cached_counter;
static uint32_t __attribute__((section(".noinit"))) s_cache_magic;
static constexpr uint32_t CACHE_VALID = 0xC0DE600D;

// In loadLast() — check cache first
uint32_t CounterStore::loadLast() {
  if (s_cache_magic == CACHE_VALID) {
    last_counter_ = s_cached_counter;
  } else {
    load();  // full scan on cold boot only
    s_cache_magic = CACHE_VALID;
  }
  s_cached_counter = last_counter_;
  return last_counter_;
}

// In update() — keep cache in sync
void CounterStore::update(uint32_t counter) {
  // ... existing write logic ...
  s_cached_counter = counter;
}
```

---

## 2. Button Press Timing Offset — Valid

**Claimed problem:** `wait_for_button_press_release()` runs after boot init (~100-200ms). The button press that woke the device is already in progress, so measured duration is shorter than actual. 1000ms long-press threshold effectively requires ~1200ms of physical holding.

**Evaluation:** Confirmed. Boot path before `wait_for_button_press_release()` at `Uguisu/main.cpp:107` includes `delay(50)`, LittleFS init, key load, and `Bluefruit.begin()`. The button is already LOW when the timing starts. Measured press is shorter than physical press by the boot time.

**Fix:** Record boot start time and compensate.

```cpp
// At top of setup()
const uint32_t boot_start = millis();

// When measuring press duration (line 107-110)
const uint32_t press_ms = wait_for_button_press_release(UGUISU_BUTTON_TIMEOUT_MS);
if (press_ms == 0) system_off();
const uint32_t compensated_ms = press_ms + (millis() - boot_start - press_ms);
// Simpler: just add boot overhead directly
const uint32_t total_ms = press_ms + boot_start;  // boot_start ≈ time spent in init
const immo::Command command =
    (total_ms >= UGUISU_LONG_PRESS_MS) ? immo::Command::Lock : immo::Command::Unlock;
```

Alternative simpler fix: just lower the threshold to 800ms to account for typical boot time.

---

## 3. Button Timeout Excessive — Valid, misleading framing

**Claimed problem:** 10 seconds awake at ~5mA waiting for a button press that already triggered the wake. 2-3 seconds is sufficient.

**Evaluation:** The 10s timeout (`uguisu_nrf52840.h:33`) only matters when the button is NOT pressed when code reaches the check (noise wake, or user released during boot). In normal operation, the button is already LOW and the code proceeds immediately to timing the release — the 10s is never reached. The framing suggests energy waste on every press, which doesn't happen.

**Fix:** Reduce to 2-3 seconds. Low-risk change, saves power only on accidental wakes.

```cpp
#define UGUISU_BUTTON_TIMEOUT_MS 2000
```

---

## 4. FreeRTOS LED Task Overkill — Valid, irrelevant in practice

**Claimed problem:** Spawns a FreeRTOS task with 512 bytes of stack just to blink a blue LED during provisioning.

**Evaluation:** Confirmed at `Uguisu/main.cpp:92`. But this only runs when USB-connected for provisioning — never during battery operation. Zero impact on battery life or production use. The 512 bytes is trivial on the nRF52840's 256KB RAM.

**Fix (if desired):** Replace with a FreeRTOS software timer.

```cpp
static TimerHandle_t g_prov_led_timer = nullptr;
static void prov_led_cb(TimerHandle_t) { led::prov_pulse_step(); }

// In setup(), replace xTaskCreate with:
g_prov_led_timer = xTimerCreate("prov", pdMS_TO_TICKS(30), pdTRUE, nullptr, prov_led_cb);
xTimerStart(g_prov_led_timer, 0);

// Cleanup: xTimerDelete(g_prov_led_timer, 0);
```

Requires refactoring `led::prov_pulse()` into a non-blocking step function. Low priority.

---

## 5. Blocking the BLE Stack — Valid, low practical impact

**Claimed problem:** `handle_valid_command()` plays buzzer tones using blocking `delay()` inside `scan_callback`, stalling the BLE scanner for ~260ms.

**Evaluation:** Confirmed. `Guillemot/main.cpp:34-38` uses `delay(duration_ms)`. Two tones (130ms each) + latch pulse (15ms) = ~275ms blocking inside the radio callback. However: the fob sends ~30 duplicate packets over 600ms. Only one needs to arrive before the block. Subsequent duplicates are harmless (counter already accepted). Single-fob system.

**Fix:** Decouple actuation from the BLE callback via a FreeRTOS queue.

```cpp
static QueueHandle_t g_cmd_queue;

// In scan_callback: push payload instead of acting
void scan_callback(ble_gap_evt_adv_report_t* report) {
  immo::Payload pl{};
  if (!parse_payload_from_report(report, pl)) return;
  if (key_is_all_zeros()) return;
  if (!verify_payload(pl)) return;
  xQueueSend(g_cmd_queue, &pl, 0);  // non-blocking
}

// Dedicated task consumes queue
void immo_task(void*) {
  immo::Payload pl;
  for (;;) {
    if (xQueueReceive(g_cmd_queue, &pl, portMAX_DELAY)) {
      handle_valid_command(pl);
    }
  }
}

// In setup():
g_cmd_queue = xQueueCreate(2, sizeof(immo::Payload));
xTaskCreate(immo_task, "immo", 256, nullptr, 1, nullptr);
```

---

## 6. Continuous 5% Duty Cycle — Valid, non-issue

**Claimed problem:** 25ms/500ms scan draws ~250µA average, a constant vampire drain on the scooter battery.

**Evaluation:** Confirmed. But at 250µA on a 15Ah battery: 6mAh/day = 0.04% per day. The scooter would need to sit for ~7 years to drain from scanning alone. Gemini acknowledges this is "acceptable."

**Fix:** Not needed. The current duty cycle is already well-optimized for latency vs. power.

---

## 7. No Watchdog on Guillemot — Valid, CRITICAL

**Claimed problem:** No WDT configured. If firmware hangs (SoftDevice error, flash corruption, radio lockup), the scooter stays in whatever state it was in — potentially unlocked indefinitely.

**Evaluation:** Confirmed. No WDT configuration anywhere in the Guillemot codebase. `loop()` at line 137 is just `sd_app_evt_wait()`. If events stop arriving, the loop sleeps forever. The SR latch holds its last state. This is the most important finding in the entire review.

**Fix:** Configure the nRF52840 WDT. The SoftDevice supports WDT coexistence.

```cpp
#include <nrf_wdt.h>

static nrf_drv_wdt_channel_id g_wdt_channel;

void wdt_event_handler(void) {
  // On WDT timeout: system resets. Latch stays in current state.
  // After reboot, Guillemot re-enters locked scanning mode.
}

// In setup(), after Bluefruit.Scanner.start():
nrf_drv_wdt_config_t config = NRF_DRV_WDT_DEAFULT_CONFIG;
config.reload_value = 8000;  // 8 second timeout
nrf_drv_wdt_init(&config, wdt_event_handler);
nrf_drv_wdt_channel_alloc(&g_wdt_channel);
nrf_drv_wdt_enable();

// In loop() or scan_callback:
nrf_drv_wdt_channel_feed(g_wdt_channel);
```

The WDT must be fed from the main loop or a timer. If `sd_app_evt_wait()` returns events normally, the WDT gets fed. If the system locks up, the WDT resets the MCU after 8 seconds, re-entering the locked scanning state.

---

## 8. `ccm_mic_8()` Return Value Unchecked — WRONG

**Claimed problem:** `verify_payload()` may not check the return value of `ccm_mic_8()`, potentially comparing against an uninitialized buffer.

**Evaluation:** The return value IS checked. `Guillemot/main.cpp:63-64`:

```cpp
if (!immo::ccm_mic_8(g_psk, nonce, msg, sizeof(msg), expected)) return false;
```

The payload is rejected immediately on failure. The reviewer either examined an older version or missed this line.

**Fix:** None needed. Code is already correct.

---

## 9. Nonce Lacks Session Diversifier — Valid, low practical risk

**Claimed problem:** Nonce is `LE32(counter) || 0x00×9`. If the same key is re-provisioned with a counter reset, nonce reuse breaks CCM.

**Evaluation:** Confirmed at `immo_crypto.cpp:35-38`. The 9 zero bytes are wasted. However, Whimbrel generates a new random key each provisioning, so the same (key, nonce) pair only recurs if someone deliberately provisions the same key twice. Low practical risk.

**Fix:** Generate a random 4-byte session ID during provisioning. Store alongside the key. Include in nonce bytes 4-7.

```cpp
// immo_crypto.cpp
void build_nonce(uint32_t counter, const uint8_t session_id[4], uint8_t nonce[NONCE_LEN]) {
  le32_write(&nonce[0], counter);
  memcpy(&nonce[4], session_id, 4);
  for (size_t i = 8; i < NONCE_LEN; i++) nonce[i] = 0;
}
```

Requires adding session_id to the provisioning payload format and storage. Both fob and receiver must agree on it.

---

## 10. Payload Authenticated but Not Encrypted — Valid

**Claimed problem:** Counter and command are sent in plaintext. A passive sniffer sees lock/unlock commands and counter values (usage frequency). Full CCM encryption is nearly free.

**Evaluation:** Confirmed. `Uguisu/main.cpp:128-129` copies plaintext `msg` into the payload. `ccm_mic_8()` only computes the CBC-MAC tag, not the CTR-mode keystream for encryption. A sniffer sees which command was sent and the counter value. However, this doesn't enable attacks — you can't forge a MIC without the key.

**Fix:** Extend `ccm_mic_8()` to also produce the CTR-mode keystream and XOR it with the plaintext. Rename to `ccm_encrypt_8()`.

```cpp
// After computing the MIC (existing code), add CTR encryption:
// Generate keystream blocks A1, A2, ... and XOR with plaintext
for (uint16_t ctr_i = 1; offset_enc < msg_len; ctr_i++) {
  uint8_t ai[16]{};
  ai[0] = static_cast<uint8_t>(L - 1);
  memcpy(&ai[1], nonce, NONCE_LEN);
  ai[14] = static_cast<uint8_t>((ctr_i >> 8) & 0xFF);
  ai[15] = static_cast<uint8_t>(ctr_i & 0xFF);

  uint8_t si[16]{};
  if (!aes128_ecb_encrypt(key, ai, si)) return false;

  const size_t n = min((size_t)16, msg_len - offset_enc);
  for (size_t j = 0; j < n; j++)
    out_ct[offset_enc + j] = msg[offset_enc + j] ^ si[j];
  offset_enc += n;
}
```

Requires corresponding decryption on the receiver side before MIC verification. Cost: one additional AES block (5-byte message fits in one block).

---

## 11. Manual CCM Instead of Hardware NRF_CCM — MISLEADING

**Claimed problem:** The code manually implements CCM via ECB loops. The nRF52840 has a hardware NRF_CCM peripheral that should be used instead.

**Evaluation:** The nRF52840 SoftDevice (S140) **reserves the CCM, AAR, and ECB peripherals for its own use**. Direct access to `NRF_CCM` is blocked. The only crypto API available to application code is `sd_ecb_block_encrypt()`, which is exactly what the code uses. There is no higher-level SoftDevice CCM API for application use. The manual ECB-based CCM implementation is the standard and correct approach on nRF52 with SoftDevice.

**Fix:** None needed. The code is already doing the only thing possible without ditching the SoftDevice.

---

## 12. Counter Log Rotation Power-Failure Bug — Valid, SECURITY BUG

**Claimed problem:** `rotateIfNeeded_()` does `remove(old)` → `rename(current → old)`. If power fails after the rename but before `update()` writes to the new log, `load()` reads the current log (doesn't exist), sets `last_counter_ = 0`, and never reads the old log. Counter resets, enabling replay.

**Evaluation:** Confirmed. `immo_storage.cpp:73-81`: after rotation, `log_path_` doesn't exist. `load()` at line 34-44 only opens `log_path_`. It never reads `old_log_path_`. If `log_path_` doesn't exist, `last_counter_` stays 0. Both Uguisu and Guillemot share this code and are vulnerable.

**Fix:** Scan both files in `load()`, take the maximum.

```cpp
void CounterStore::load() {
  last_counter_ = 0;
  scan_file_(log_path_);
  scan_file_(old_log_path_);
}

void CounterStore::scan_file_(const char* path) {
  Adafruit_LittleFS_Namespace::File f(InternalFS.open(path, Adafruit_LittleFS_Namespace::FILE_O_READ));
  if (!f) return;

  CounterRecord rec{};
  while (f.read(reinterpret_cast<void*>(&rec), sizeof(rec)) == sizeof(rec)) {
    if (record_crc(rec.counter) != rec.crc32) continue;
    if (rec.counter > last_counter_) last_counter_ = rec.counter;
  }
}
```

Add `void scan_file_(const char* path);` to the private section of `CounterStore` in the header.

---

## 13. No Delivery Confirmation — Valid, inherent tradeoff

**Claimed problem:** Fob broadcasts for 600ms and sleeps with no acknowledgment. User gets zero feedback if out of range.

**Evaluation:** Confirmed. The LED on the fob confirms "I sent it," not "they got it." However, adding confirmation requires a connection or back-channel scanner, which would dramatically increase power consumption and complexity. Most car key fobs have the same limitation. This is a deliberate architectural tradeoff, not an oversight.

**Fix:** If desired, add a brief scanner on the fob to listen for an ACK advertisement from Guillemot. Cost: ~50-100ms additional active time per press, plus code on both sides. Probably not worth the complexity for a scooter fob.

---

## 14. Company ID 0xFFFF — Partially valid

**Claimed problem:** 0xFFFF is the BT SIG test/unregistered ID. Other devices using it trigger full MIC checks before rejection.

**Evaluation:** `guillemot_nrf52840.h:14` confirms `MSD_COMPANY_ID = 0xFFFF`. But `Guillemot/main.cpp:128` calls `Bluefruit.Scanner.filterMSD(MSD_COMPANY_ID)`, which filters at the radio level. Only matching advertisements trigger the callback. Random 0xFFFF devices in the wild are rare. For production, a registered ID is proper. For prototyping, fine.

**Fix:** For production, either register a Bluetooth SIG company ID ($7,500/year) or add a magic-byte prefix to the MSD payload for cheaper filtering:

```cpp
// Add 2-byte magic after company ID
static constexpr uint16_t IMMOGEN_MAGIC = 0x494D;  // "IM"

// In parse_payload_from_report: check magic before parsing
if (msd[2] != (IMMOGEN_MAGIC & 0xFF) || msd[3] != (IMMOGEN_MAGIC >> 8)) return false;
```

Increases MSD size by 2 bytes (15 → 17), still within BLE limits.

---

## 15-17. Hardware Documentation Errors — Very likely valid

**Claimed problem:** The technical documentation (`18-CODEBASE_TECHNICAL_DOCUMENTATION.md`) misrepresents the Guillemot PCB in three ways:

1. **MOSFET topology:** Doc shows `Drain ← +BATT, Source → ESC-` (high-side N-FET). An N-FET high-side switch with 42V on the source needs Vg > 46V to turn on. The 10V gate drive can't do this. The actual design must be a low-side switch (Drain ← ESC-, Source → GND, Vgs = 10V).

2. **10V rail purpose:** Doc describes Q3 (P-FET) as a "bleeder" and D2's 10V Zener as being "on the regulated rail." Gemini claims Q3 actually switches +BATT through a Zener to create a 10V gate-drive rail for Q1, with zero quiescent draw when locked.

3. **P-FET gate protection:** Doc doesn't explain how Q3 survives with Source at 42V. Without clamping, Vgs could reach -42V, exceeding the SI2309CDS's -20V max. D1 (12V Zener) must be clamping Vgs, but the doc says D1 "clamps buck input."

**Evaluation:** Cannot verify directly against the KiCad binary schematic, but the electrical arguments are sound. The documented topology is electrically impossible as described. The 10V gate drive only works for a low-side switch.

**Fix:** Rewrite Section 6 of `18-CODEBASE_TECHNICAL_DOCUMENTATION.md`. The signal flow diagram should show:

```
Q1 (IPB042N10N3G) — LOW-SIDE SWITCH:
  Drain ← ESC- (load return path)
  Source → GND (battery negative)
  Gate  ← ISO_GATE (10V when unlocked, 0V when locked)

Q3 (SI2309CDS) — 10V GATE DRIVE SWITCH:
  Source ← +BATT
  Drain  → R5 + D2 (10V Zener) → 10V_RAIL → Q1 gate
  Gate   ← D1 (12V Zener clamp) ← Q4 (2N7002) ← Q_UNLOCK
  Purpose: Switches battery through Zener regulator to create 10V gate drive.
           Zero quiescent current when locked (Q3 off, no current path).

D1 (BZT52C12-7-F) — GATE PROTECTION:
  Clamps Q3 Vgs to -12V (within SI2309CDS -20V abs max).
  NOT for "clamping buck input."
```

Verify these connections against the actual KiCad schematic before committing.

---

## 18. Hardware Design Issues — Valid, production hardening

**Claimed problem:** Five hardware issues identified: no reverse polarity protection, TVS overshoot, dual-NPN buzzer driver, no ESD protection, no conformal coating.

**Evaluation:** All are legitimate engineering concerns for a production design. None are showstoppers for a prototype.

**Fixes:**

- **Reverse polarity:** Add a P-FET ideal diode or Schottky on +BATT input. Schottky (e.g., SS54) is simplest; P-FET (e.g., SI2301) gives lower drop.
- **TVS overshoot:** Verify D1 Zener can handle the transient current during a TVS clamp event. If not, upsize D1 or add a second TVS stage.
- **Buzzer driver:** Replace high-side Q5 (NPN) with a PNP (e.g., MMBT3906). Or simplify to a single low-side N-FET.
- **ESD protection:** Add PESD5V0S2BT or similar on D0, D1, D3 lines.
- **Conformal coating:** Specify in production documentation. MG Chemicals 419D or similar.

All are schematic/BOM changes. No firmware modifications needed.

---

## 19. Extremely Short Button Presses (< 200ms) — Valid, missed UX edge case

**Claimed problem (User):** What happens if the user presses the button too short (shorter than 200ms)? The device wakes up but might miss the press. Can we make it unlock in that scenario?

**Evaluation:** Very valid. When the fob wakes from `system_off`, the boot process takes ~100-200ms. If the user releases the button before `wait_for_button_press_release()` starts, the pin is already HIGH. The function's first `while` loop will then sit there for 10 seconds waiting for a *new* press, eventually timing out and sleeping. The quick press is completely ignored.

**Fix:** Since the only wake source from `system_off` is the button, we *know* a press occurred if we just booted. If the button is already HIGH when we check it, we can immediately return a small duration (e.g., 1ms) to trigger an immediate Unlock, rather than waiting 10 seconds.

```cpp
// In wait_for_button_press_release(), after initial boot:
if (digitalRead(UGUISU_PIN_BUTTON) != LOW) {
  // Pin already HIGH. We woke from sleep but user already released.
  // Treat as a very short press (Unlock).
  return 1; 
}
```

---

## 20. Early Exit on Long Press (> 1s) — Valid, UX improvement

**Claimed problem (User):** What happens if the user presses the button too long? Can we just set a timeout once it hits 1 sec and proceed to locking without waiting for release?

**Evaluation:** Valid. Currently, `wait_for_button_press_release()` blocks until the user *releases* the button, up to the 10-second timeout. If the user holds the button for 3 seconds, they get zero LED feedback until they let go. Waiting for release is unnecessary once the 1000ms `UGUISU_LONG_PRESS_MS` threshold is crossed.

**Fix:** Break out of the polling loop immediately once the duration exceeds the long-press threshold. This provides instant LED feedback exactly at 1 second, making the fob feel much more responsive.

```cpp
const uint32_t press_start = millis();
while (millis() < deadline && digitalRead(UGUISU_PIN_BUTTON) == LOW) {
  if (millis() - press_start >= UGUISU_LONG_PRESS_MS) {
    // Threshold reached, no need to wait for release
    return UGUISU_LONG_PRESS_MS; 
  }
  delay(10);
}
return millis() - press_start;
```

---

## Priority Summary

| Priority | Item | Action |
|---|---|---|
| **P0** | #7 No watchdog | Add WDT to Guillemot immediately |
| **P0** | #12 Rotation power-failure bug | Fix `load()` to scan both files |
| **P1** | #15-17 Hardware doc errors | Rewrite Section 6 of technical docs |
| **P2** | #10 No encryption | Add CTR-mode encryption to CCM |
| **P2** | #2 Button timing offset | Compensate or lower threshold |
| **P2** | #18 Hardware hardening | Address for production revision |
| **P2** | #19 Short press missed | Fix `wait_for_button_press_release` to assume Unlock if already HIGH |
| **P2** | #20 Long press delayed UX | Early exit from polling loop at 1000ms |
| **P3** | #1 LittleFS cache | Add noinit RAM cache |
| **P3** | #5 BLE blocking | Decouple with FreeRTOS queue |
| **P3** | #9 Nonce diversifier | Add session ID to provisioning |
| **P3** | #14 Company ID | Add magic prefix or register ID |
| Skip | #3 Button timeout | Trivial config change if desired |
| Skip | #4 FreeRTOS LED task | No real-world impact |
| Skip | #6 Duty cycle | Non-issue on scooter battery |
| N/A | #8 Return value check | Already correct, no action |
| N/A | #11 Hardware CCM | Not possible with SoftDevice |
| N/A | #13 Delivery confirmation | Architectural tradeoff, not a bug |

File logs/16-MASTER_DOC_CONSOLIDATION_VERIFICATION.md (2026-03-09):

# Master Document Consolidation & Verification

**Last modified: 2026-03-10 01:28**

**Date:** 2026-03-10
**Status:** COMPLETE — Master document deleted, all content verified in monorepo.

---

## Context

A standalone master document (`BLE_Immobilizer_G30_Detailed(10).md`) existed at the project root alongside the Immogen monorepo. This document contained system-level design specifications for the three-part immobilizer (Uguisu fob, Guillemot receiver, Whimbrel web app). To reduce maintenance burden and prevent documentation drift, a consolidation audit was performed to verify all content existed in the monorepo before deletion.

---

## Audit Scope

The master document covered eight major sections:

1. **Overview** — System architecture, deck placement, signal diagram
2. **BLE Protocol** — Advertisement-based messaging, 9-byte payload spec
3. **Uguisu (Key Fob)** — Hardware BOM (~$10), firmware boot flow, power budget
4. **Guillemot (Deck Receiver)** — Hardware specs, PCB layout, signal flow, BOM (~$25–30)
5. **Whimbrel (Provisioning App)** — Web Serial protocol, security model, key generation
6. **Build Notes** — Assembly, conformal coating, buzzer timing
7. **Design Notes** — Component rationale (AO3422, POR circuit, gate isolation, MOSFET selection, NVS wear)
8. **TBD** — Pending items (enclosure CAD, validation)

---

## Coverage Analysis

### Section-by-Section Mapping

| Master Section | Repo Location | Status | Notes |
|---|---|---|---|
| **Overview** | `README.md` § Overview | ✅ COMPLETE | Identical ASCII diagram and system description |
| **BLE Protocol** | `README.md` § BLE Protocol | ✅ COMPLETE | Updated with company ID offset spec |
| **Uguisu BOM** | `Uguisu/README.md` § Hardware | ✅ COMPLETE | Upgraded to 400 mAh LiPo + new switch/LED |
| **Uguisu firmware** | `Uguisu/README.md` § Software | ✅ COMPLETE | Detailed boot flow pseudocode (lines 76–109) |
| **Guillemot hardware/BOM** | `Guillemot/README.md` § Hardware | ✅ COMPLETE | Comprehensive BOM with all passives |
| **PCB layout specs** | `Guillemot/README.md` § PCB Layout | ✅ COMPLETE | All 6 critical specs present (GND jumper, clearance, RF keepout, etc.) |
| **Signal flow** | `Guillemot/README.md` § Operation | ✅ COMPLETE | Unlock/lock/power flows documented |
| **Design notes (7 items)** | `Guillemot/README.md` § Design Notes | ✅ COMPLETE | AO3422 rationale, POR circuit, gate isolation, MOSFET selection, all present |
| **NVS wear** | `Uguisu/README.md` § Design Notes | ✅ COMPLETE | 2.7 years / wear-leveling documented |
| **EasyEDA→KiCad** | Both READMEs | ✅ COMPLETE | Tool reference and usage present |
| **Whimbrel security** | `Guillemot/README.md` § Onboarding + `Uguisu/README.md` § Onboarding | ✅ COMPLETE | Write-only security, physical presence requirement documented |
| **Whimbrel ephemeral keys** | `Whimbrel/README.md` § Ephemeral Memory | ✅ COMPLETE | More detailed than master (includes device-replacement scenario) |
| **TBD items** | `README.md` § TBD | ✅ COMPLETE | Enclosure CAD + validation identical |

### Discrepancies & Corrections

The master document contained **outdated values** that have been corrected in the repo based on real measurement and analysis:

| Parameter | Master Doc | Repo Docs | Source |
|---|---|---|---|
| **Guillemot locked current** | ~22 μA | ~306 μA | `logs/15-BLE_POWER_ANALYSIS_AND_DOCUMENTATION_DISCREPANCY.md` |
| **Uguisu standby current** | < 5 μA | ~30 μA | Includes XIAO charging IC |
| **Uguisu per-press energy** | ~0.004 mAh | ~0.006 mAh | Real measurement via PPK2 |
| **Uguisu battery capacity** | 100 mAh | 400 mAh | Hardware upgrade (TW-502535 vs. generic) |
| **Guillemot scan duty cycle** | 20 ms / 2 s (1%) | 25 ms / 500 ms (5%) | Updated for better detection (see logs/8, logs/11) |

These corrections reflect iterative refinement through:
- Power analysis (logs/15)
- Architecture review & critique (logs/7)
- BLE timing simulation (logs/10)
- Build validation and real-world testing

### Minor Items Not in Repo

Three items appeared exclusively in the master document:

1. **Conformal coating instructions** — "Conformal coat PCB (exclude USB-C, XT60 joints, and buzzer port). Drill 3 mm acoustic port + mesh in scooter battery box for BZ1."
   - **Status:** Discarded. User opted not to conformal coat final build.

2. **QSPI flash sleep (0xB9)** — Firmware detail: `nrf_qspi_mem_object_read(0, sizeof(...))`; `nrf_qspi_mem_deep_power_down()`; `sd_power_system_off()`.
   - **Status:** Discarded. Not utilized in firmware; firmware code is authoritative.

3. **Whimbrel ephemeral session keys** — "Closing the tab permanently deletes the session key."
   - **Status:** Already in `Whimbrel/README.md` § Ephemeral Memory (lines 30–32), more comprehensive.

---

## Conclusion

✅ **All actionable content from the master document is present in the monorepo.**

The distributed documentation is **more accurate and comprehensive** than the master document:
- **Immogen/README.md** — System overview, repository structure, protocol spec
- **Immogen/Guillemot/README.md** — Receiver design, PCB layout, operation, design rationale
- **Immogen/Uguisu/README.md** — Fob design, GPIO mapping, LED behavior, boot flow
- **Whimbrel/README.md** — Provisioning protocol, security model, ephemeral key storage
- **Immogen/logs/** — 15+ technical deep-dives, architecture reviews, migration guides, power analysis

**Master document deleted:** 2026-03-10.

---

## Recommended Reading Order

For new contributors:

1. `Immogen/README.md` — Start here for system overview
2. `Immogen/Guillemot/README.md` — Receiver hardware & firmware
3. `Immogen/Uguisu/README.md` — Fob hardware & firmware
4. `Whimbrel/README.md` — Provisioning workflow
5. `Immogen/logs/2-CODEBASE_TECHNICAL_WRITEUP.md` — Deep technical reference
6. `Immogen/logs/15-BLE_POWER_ANALYSIS_AND_DOCUMENTATION_DISCREPANCY.md` — Power budget derivation

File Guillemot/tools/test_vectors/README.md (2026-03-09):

# Test vectors (receiver)

MIC test vectors are maintained at repo root:

```
tools/test_vectors/
```

See [Immogen tools/test_vectors](https://github.com/LPFchan/Immogen/tree/main/tools/test_vectors) for usage.

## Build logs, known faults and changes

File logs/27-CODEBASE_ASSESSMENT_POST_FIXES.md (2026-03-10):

# Codebase Assessment — Post-Fix Review

*Date: 2026-03-10*

---

## 1. `ensure_provisioned()` — Inverted Retry Loop

**File:** `lib/immo_provisioning.cpp:143`

`key_is_all_zeros` returns `true` when the key IS blank. The `!` negation flips this:

| State | Loop runs? | Expected |
|---|---|---|
| Key blank (needs provisioning) | No | Yes |
| Key valid (provisioned) | Yes | No |

The safety-net retry loop is backwards. Low impact in practice (first 30-sec window handles most cases; VBUS disconnect exits the loop), but the documented behaviour — "loop indefinitely until provisioning succeeds" — is broken.

**Fix:** Remove the `!` and rename the parameter to match what the callback actually does:

```cpp
// immo_provisioning.h
bool (*is_unprovisioned)()  // returns true when key is blank

// immo_provisioning.cpp
while (is_unprovisioned && is_unprovisioned() && prov_is_vbus_present()) {
```

---

## 2. `gen_mic.py` — Stale After CCM Encryption Fix

**File:** `tools/test_vectors/gen_mic.py:57-61`

The script still outputs the pre-Fix-#5 format (full plaintext + tag). The firmware now outputs `counter_plain(4) + command_encrypted(1) + mic(8)`.

Worse, the firmware's CCM AAD handling is non-standard: all 5 bytes go into CBC-MAC as "message," and only byte 4 is encrypted using `S1[0]` (not `S1[4]` as standard CCM would). The Python `cryptography.AESCCM` class cannot replicate this with standard parameters — a drop-in fix isn't possible.

**Fix options:**
1. Reimplement the script with manual CCM matching the firmware's construction
2. Migrate the firmware to standard RFC 3610 AAD formatting (see trade-off below)
3. At minimum, add a disclaimer to the script and a comment in `immo_crypto.cpp`:

```cpp
// Non-standard CCM: full msg (counter + command) feeds CBC-MAC as "message" with no AAD block.
// Only bytes [aad_len:] are counter-encrypted, starting at S1[0].
// Differs from RFC 3610 but is cryptographically sound for this use case.
```

**RFC 3610 migration trade-off:**

| | Notes |
|---|---|
| **Pro** | `gen_mic.py` fixed trivially — pass `aad=counter_bytes` to Python's `AESCCM`, no manual reimplementation |
| **Pro** | Any RFC 3610-compliant library verifies payloads out of the box |
| **Pro** | Code maps 1:1 to the spec; straightforward to audit |
| **Pro** | Extending AAD fields (device ID, firmware version) is well-defined |
| **Con** | Breaking change — B0 flags change (`0x19` → `0x59`), extra CBC-MAC block added, MIC values change entirely. Both devices must be reflashed simultaneously |
| **Con** | One extra AES-ECB call per operation (50% more CBC-MAC blocks for this message size) |
| **Con** | `msg_len` in B0 must change from 5 to 1; incorrect values silently break MIC generation |
| **Con** | Risk of introducing a bug while migrating a working crypto implementation |

---

## 3. `readVbat_mv()` — Single ADC Sample Near Threshold

**File:** `Uguisu/firmware/include/uguisu_nrf52840.h:59`

SAADC noise is ~±15 mV at this scaling. At the 3400 mV low-battery threshold, consecutive presses can alternate between normal and low-battery LED feedback.

**Fix:** 4-sample average, ~4 ms overhead:

```cpp
uint32_t sum = 0;
for (int i = 0; i < 4; i++) { sum += analogRead(UGUISU_VBAT_PIN); delay(1); }
const uint16_t mv = (uint16_t)((sum / 4) * 6000u / 4096u);
```

---

## 4. No Firmware Version in Boot Message

Neither firmware identifies its version over serial. Undiagnosable in the field without reflashing.

**Fix:** `Serial.println("BOOTED:Guillemot-" __DATE__);`

---

## 5. CI Has No Test Step

`release.yml` compiles both firmwares but runs no validation. Crypto regressions would ship silently.

**Fix:** Add a step running `gen_mic.py` against known-good vectors once the script is updated.

---

| Priority | Item |
|---|---|
| High | `ensure_provisioned` retry loop logic |
| High | `gen_mic.py` stale test vectors |
| Medium | Battery ADC averaging |
| Medium | Firmware version in boot message |
| Low | CCM non-standard construction comment |
| Low | CI test step |

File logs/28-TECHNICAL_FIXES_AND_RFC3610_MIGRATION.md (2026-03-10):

# Technical Update: Crypto Standardization & Logic Fixes

**Date:** 2026-03-10
**Scope:** `immo_crypto` (RFC 3610), `immo_provisioning` logic, Fob stability, CI/CD validation.

---

## 1. RFC 3610 Cryptography Migration
Migrated from a custom CCM-like construction to standard **RFC 3610** to enable interoperability with standard libraries and improve auditability.

*   **Changes:**
    *   **AAD:** The 4-byte counter is now treated as Additional Authenticated Data (AAD) rather than message plaintext.
    *   **Formatting:** Updated B0 block flags (`Adata=1`) and inserted standard AAD length headers.
    *   **Encryption:** Only the 1-byte command is now counter-encrypted; the 4-byte counter remains plaintext but authenticated.
*   **Impact:** **Breaking change.** All devices must be reflashed. Tooling (`gen_mic.py`) now uses standard `cryptography.AESCCM`.

---

## 2. Provisioning Loop Fix
Corrected an inverted condition in `ensure_provisioned()` where the MCU would exit the provisioning loop when the key was blank, instead of staying trapped until successful setup.
*   **Fix:** Removed the `!` negation and renamed callback to `is_unprovisioned()` for clarity.

---

## 3. Hardware Stability: ADC Averaging
To prevent "flickering" low-battery LED indications caused by SAADC noise (~±15 mV), `readVbat_mv()` now uses a **4-sample average** with 1ms intervals. This smooths jitter near the 3.4V threshold without adding perceptible lag.

---

## 4. Observability & CI/CD
*   **Versioning:** Added `__TIMESTAMP__` and hardware `DEVICEID` to serial boot messages. This identifies both the specific firmware build and the physical hardware without requiring external scripts or libraries.
*   **CI Validation:** Added a `Verify Cryptography Implementation` step to `.github/workflows/release.yml`. It validates the current build against a "Golden Vector" using `gen_mic.py`, preventing cryptographic regressions.

---

## 5. File Summary
| Component | Affected Files |
| :--- | :--- |
| **Crypto** | `lib/immo_crypto.cpp`, `tools/test_vectors/gen_mic.py` |
| **Provisioning** | `lib/immo_provisioning.h/cpp`, `*/main.cpp` |
| **Stability** | `Uguisu/firmware/include/uguisu_nrf52840.h` |
| **CI/CD** | `.github/workflows/release.yml` |

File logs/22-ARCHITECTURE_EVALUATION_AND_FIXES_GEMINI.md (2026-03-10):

# Immogen Architecture Evaluation & Fix Plan

*Date: 2026-03-10*

This document evaluates the architectural critiques from the combined review (`21-ARCHITECTURE_CRITIQUE_COMBINED.md`), filters out invalid claims, and outlines actionable fixes for the valid issues.

## 1. Uguisu (Key Fob) Firmware

### The LittleFS Power Drain
*   **Problem:** On every wake from `system_off`, `immo_storage::load()` sequentially reads the entire LittleFS counter log to find the latest anti-replay counter, wasting CPU cycles and battery.
*   **Validity:** **Valid.** `immo_storage.cpp` uses a linear `while (f.read(...))` loop. Since the fob restarts from deep sleep on every press, this linear scan happens on every use.
*   **Fix:** Utilize nRF52 General Purpose Retention Registers (`GPREGRET`) or `.noinit` RAM to cache the counter across `system_off` sleeps. Only scan LittleFS on a cold boot (battery insertion). Alternatively, use a raw flash page with a binary search instead of a full filesystem.

### Button Press Timing Offset
*   **Problem:** `wait_for_button_press_release()` runs after boot initialization (~100-200 ms). The physical press is longer than the measured press, making the 1000 ms long-press threshold effectively ~1200 ms.
*   **Validity:** **Valid.** The nRF52 wakes from `system_off()` with a reset. `setup()` takes time before polling the button.
*   **Fix:** Subtract an estimated boot time offset (e.g., 150 ms) from the duration calculated in `wait_for_button_press_release()`, or simply document the true physical threshold for users.

### Excessive Button Timeout
*   **Problem:** The 10-second wait for button release (`UGUISU_BUTTON_TIMEOUT_MS`) drains battery unnecessarily if a button is accidentally held down in a pocket.
*   **Validity:** **Valid.** The system stays awake drawing ~5 mA for up to 10 seconds.
*   **Fix:** Reduce `UGUISU_BUTTON_TIMEOUT_MS` from 10000 to 2000-3000 ms.

### Overkill FreeRTOS Task for Provisioning LED
*   **Problem:** Uguisu spawns a dedicated FreeRTOS task with a 512-byte stack just to blink a blue LED during USB provisioning.
*   **Validity:** **Valid.** While `ensure_provisioned()` blocks the main loop reading serial, an entire FreeRTOS task for an LED is heavy.
*   **Fix:** Use a non-blocking hardware timer/interrupt approach, or simply accept the minor overhead since it only occurs when plugged into USB power.

## 2. Guillemot (Receiver) Firmware

### Blocking the BLE Stack
*   **Problem:** `handle_valid_command()` blocks for hundreds of milliseconds using `buzzer_tone_ms()` (which uses `delay()`) from within the Bluefruit `scan_callback`.
*   **Validity:** **Valid.** `scan_callback` runs in a high-priority context. Blocking it stalls the BLE scanner, causing dropped packets.
*   **Fix:** Decouple actuation. Have `scan_callback` push valid commands to a FreeRTOS queue. A dedicated `ImmoTask` should consume the queue and handle latch/buzzer timing asynchronously.

### Missing Watchdog Timer (WDT)
*   **Problem:** Guillemot is an always-on safety device. If the firmware hangs, it stays in its current state forever.
*   **Validity:** **Valid.** No WDT is initialized in `Guillemot/firmware/src/main.cpp`.
*   **Fix:** Enable the nRF52840 hardware WDT with a suitable timeout (e.g., 5 seconds) and pet it in the idle loop or a dedicated task.

## 3. Cryptography & Security

### `verify_payload()` Not Checking `ccm_mic_8()` Return Value
*   **Problem:** Claimed that `verify_payload()` ignores the return value of `ccm_mic_8()`, potentially comparing against an uninitialized buffer if the SoftDevice ECB call fails.
*   **Validity:** **INVALID (BULLSHIT).** The codebase explicitly checks the return value in `Guillemot/firmware/src/main.cpp` line 64: `if (!immo::ccm_mic_8(g_psk, nonce, msg, sizeof(msg), expected)) return false;`. This claim is completely false and has been discarded.

### Missing Session Diversifier in Nonce
*   **Problem:** The CCM nonce pads 9 bytes with zeros. If a key is reused but the counter resets, the nonce repeats, breaking AES-CCM security.
*   **Validity:** **Valid.**
*   **Fix:** Generate 9 random bytes during the USB provisioning process, store them alongside the 16-byte key, and use them as the nonce suffix instead of zeros.

### Unencrypted Payload
*   **Problem:** The command and counter are sent in plaintext. An eavesdropper can see usage frequency and lock/unlock actions.
*   **Validity:** **Valid.** The implementation only uses CCM for authentication (CBC-MAC), not confidentiality.
*   **Fix:** Apply the CCM keystream to encrypt the 5-byte payload.

### Manual CCM vs. Hardware/SoftDevice
*   **Problem:** The crypto implementation manually loops ECB blocks instead of using the nRF52's hardware CCM or SoftDevice CCM API.
*   **Validity:** **Valid.** `immo_crypto.cpp` does manual CBC-MAC and CTR mode using `sd_ecb_block_encrypt()`.
*   **Fix:** Migrate to `sd_ble_opt_set` or `NRF_CCM` hardware peripheral to reduce active CPU time and manual cryptographic code.

## 4. Anti-Replay & Storage

### Power-Failure Vulnerability in Log Rotation
*   **Problem:** `rotateIfNeeded_()` renames `log` to `old_log`. If power fails before the new `log` is written, `load()` finds no `log` file and resets the counter to 0, opening a massive replay vulnerability.
*   **Validity:** **Valid.** `immo_storage.cpp`'s `load()` function only opens `log_path_`. It never checks `old_log_path_` if the primary log is missing.
*   **Fix:** Modify `load()` to read *both* `log_path_` and `old_log_path_`, taking the maximum valid counter found across both files.

## 5. BLE Protocol

### Unregistered Company ID 0xFFFF
*   **Problem:** 0xFFFF triggers unnecessary MIC verification attempts for any unregistered BLE device nearby.
*   **Validity:** **Valid.**
*   **Fix:** Assign a unique random 16-bit identifier or use a magic byte sequence in the payload to filter out non-Immogen advertisements early.

### No Delivery Confirmation
*   **Problem:** Fob has no way of knowing if the receiver actually heard the command.
*   **Validity:** **Valid, but accepted limitation.**
*   **Fix:** Implementing two-way communication requires the fob to switch to scanning mode, which adds latency and power draw. The scooter's buzzer provides auditory confirmation. This may be left as-is to preserve battery.

## 6. Hardware & Documentation

### Hardware Documentation Errors
*   **Problem:** The technical documentation misrepresents the Guillemot schematic (e.g., calling Q1 a high-side switch instead of low-side, misunderstanding the 10V gate drive and Vgs clamping).
*   **Validity:** **Valid.** The schematic uses a low-side N-FET (IPB042N10N3G) with the source tied to ESC- (GND return), and the 10V rail is indeed used to drive the gate.
*   **Fix:** Rewrite Section 6 of `18-CODEBASE_TECHNICAL_DOCUMENTATION.md` to accurately reflect the schematic topology.

### Missing Hardware Protections (Guillemot)
*   **Problem:** Missing reverse polarity protection, potential TVS overvoltage on buck, sub-optimal NPN push-pull, lack of ESD protection.
*   **Validity:** **Valid.**
*   **Fix:** Update the KiCad design in a future hardware revision (e.g., add a P-FET ideal diode, use a complementary NPN/PNP pair for the buzzer, add ESD TVS arrays on exposed GPIOs).

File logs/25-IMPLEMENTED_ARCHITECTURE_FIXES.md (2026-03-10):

# Architecture Fixes Summary

*Date: 2026-03-10*

This document summarizes the architectural issues identified during the system evaluation, outlining what the issues were, why they were problematic, and how we decided to address or skip them.

## Part 1: Implemented Fixes

### 1. Hardware Documentation Inaccuracies
- **What was the issue:** The technical documentation (`18-CODEBASE_TECHNICAL_DOCUMENTATION.md`) misrepresented the Guillemot PCB's MOSFET topology, 10V rail purpose, and P-FET gate protection.
- **Why it was an issue:** The documented design was electrically impossible (e.g., describing a 10V gate drive turning on a high-side N-FET with a 42V source, which would require Vg > 46V).
- **How we fixed it:** We created `24-HARDWARE_DOCUMENTATION_CORRECTIONS.md` to correctly describe the actual design: a low-side load switch topology, a 10V gate drive derived from the battery, and a 12V Zener clamping the gate-source voltage for protection.

### 2. Button Timing & UX Limitations
- **What was the issue:** Boot time (~100-200ms) caused the measured button press duration to be shorter than the physical press. Extremely short presses (< 200ms) were ignored, long presses provided no LED feedback until release, and the timeout was excessively long (10 seconds).
- **Why it was an issue:** It created a sluggish and unpredictable user experience, with delayed feedback or missed commands.
- **How we fixed it:** 
  - Reduced the long-press threshold to 700ms and the timeout to 2000ms.
  - Updated `wait_for_button_press_release()` to instantly return a short duration if the button pin is already HIGH after boot (capturing <200ms presses).
  - Implemented an early exit from the polling loop once the duration reaches 700ms, providing instant LED feedback exactly when the long-press threshold is met.

### 3. Log Rotation Power-Failure Vulnerability
- **What was the issue:** The LittleFS counter log rotation process `rotateIfNeeded_()` renamed the current log to an old log, then created a new one. 
- **Why it was an issue:** If a power failure occurred immediately after the rename but before the new log was written, the `load()` function would find no active log, default the counter to 0, and permanently reset the counter sequence. This exposed the system to replay attacks.
- **How we fixed it:** Modified `CounterStore::load()` to scan both the active log path and the old log path on boot, taking the maximum valid counter found across both files.

### 4. MSD Magic Bytes
- **What was the issue:** The system used `0xFFFF` (the Bluetooth SIG test ID) for its Manufacturer Specific Data (MSD) company ID.
- **Why it was an issue:** Other random devices in the wild using the `0xFFFF` test ID could trigger full MIC checks on the receiver, wasting power and CPU cycles.
- **How we fixed it:** Injected a 2-byte magic prefix (`0x494D` or `"IM"`) immediately after the company ID in the MSD payload. The receiver now filters for this magic sequence before proceeding to cryptographic verification.

### 5. Payload Plaintext Leakage
- **What was the issue:** The 5-byte payload (4-byte counter + 1-byte command) was authenticated via CCM-MAC but not encrypted.
- **Why it was an issue:** A passive sniffer could read the plaintext to see which command (lock/unlock) was sent and observe the counter to track usage frequency.
- **How we fixed it:** Replaced the pure CBC-MAC generation with full CCM authenticated encryption. The counter is passed as unencrypted Additional Authenticated Data (AAD) so the receiver can derive the nonce, while the 1-byte command is encrypted using the AES-CTR keystream.

### 6. Lack of Watchdog Timer (WDT)
- **What was the issue:** The Guillemot receiver had no Watchdog Timer configured.
- **Why it was an issue:** If the firmware hung (e.g., SoftDevice error or flash stall), the MCU would sleep forever.
- **How we fixed it:** Configured the nRF52840 hardware WDT with an 8-second timeout, continuously fed by the main `loop()`. If a hang occurs, the MCU reboots cleanly. Because Guillemot uses a hardware SR latch, the scooter does not lose power mid-ride; the hardware latch physically maintains the "unlocked" state while the firmware restarts.

---

## Part 2: Issues Not Pursued (Skipped/Rejected)

### 7. LittleFS Power Drain
- **What was the issue:** It was claimed that linearly scanning up to 512 LittleFS records on every button press wastes CPU and power.
- **Why it was an issue:** Reading flash sequentially takes a few milliseconds, slightly delaying the BLE broadcast.
- **Why we skipped it:** The full scan takes only ~2-5ms, which is completely negligible compared to the ~100-200ms boot time. Adding a `.noinit` RAM cache would unnecessarily complicate the code for a tiny, immaterial power saving.

### 8. Blocking the BLE Stack
- **What was the issue:** `handle_valid_command()` plays buzzer tones using a blocking `delay()`, stalling the BLE scanner for ~275ms.
- **Why it was an issue:** The scanner cannot receive packets while blocked.
- **Why we skipped it:** The fob sends ~30 duplicate packets over a 600ms window. Only the *first* valid packet needs to be received. Blocking after the first packet is accepted is completely fine. Dropping subsequent redundant duplicates doesn't hurt anything. Adding a FreeRTOS queue to decouple this was deemed an unnecessary complication.

### 9. Nonce Lacks Session Diversifier
- **What was the issue:** The nonce lacked a session ID, potentially allowing nonce reuse if the same key is reprovisioned.
- **Why it was an issue:** Nonce reuse in CCM completely breaks the encryption.
- **Why we skipped it:** The system already generates a *new* random key every time it is provisioned. Because the key is always new, the key-nonce pair is inherently globally unique. Adding a session diversifier would be completely redundant.

### 10. FreeRTOS LED Task Overkill
- **What was the issue:** Spawning a FreeRTOS task with 512 bytes of stack just to blink a blue LED during provisioning.
- **Why it was an issue:** Claimed to be a waste of memory and RTOS resources.
- **Why we skipped it:** This code only runs when USB-connected for provisioning, never during battery operation. It has zero impact on battery life or production use, and the memory footprint is trivial on the nRF52840's 256KB RAM.

### 11. Continuous 5% Duty Cycle
- **What was the issue:** The scanner's 25ms/500ms duty cycle draws ~250µA on average.
- **Why it was an issue:** Claimed to be a vampire drain on the scooter battery.
- **Why we skipped it:** At 250µA on a 15Ah scooter battery, it draws about 0.04% per day. The scooter would need to sit for ~7 years to drain from scanning alone. The duty cycle is already well-optimized and perfectly acceptable.

### 12. Manual CCM Instead of Hardware NRF_CCM
- **What was the issue:** The firmware manually implements CCM via ECB loops instead of using the hardware `NRF_CCM` peripheral.
- **Why it was an issue:** Software crypto is theoretically slower and uses more power than hardware crypto.
- **Why we skipped it:** The nRF52840 SoftDevice (S140) reserves the `NRF_CCM` peripheral for its own use; direct application access is blocked. The manual ECB-based CCM implementation is the standard and correct approach when using the SoftDevice.

### 13. `ccm_mic_8()` Return Value Unchecked
- **What was the issue:** The critique claimed the return value of the crypto function wasn't checked.
- **Why it was an issue:** Could potentially lead to accepting an uninitialized or failed MAC.
- **Why we skipped it:** The claim was factually incorrect. The codebase already properly checked the return value and rejected the payload on failure. No fix was needed.

### 14. No Delivery Confirmation
- **What was the issue:** The fob broadcasts blindly for 600ms and goes to sleep without an acknowledgment from the receiver.
- **Why it was an issue:** The user doesn't know for sure if the scooter received the command.
- **Why we skipped it:** This is an inherent architectural tradeoff. Adding an ACK would require a connection or a back-channel scanner on the fob, which would dramatically increase power consumption, complexity, and latency without proportionate benefit.

### 15. Hardware Design Hardening (e.g., Conformal Coating)
- **What was the issue:** The critique pointed out missing production hardening features (reverse polarity protection, TVS overshoot, ESD protection, conformal coating).
- **Why it was an issue:** These are best practices for mass production reliability.
- **Why we skipped it:** While well noted for future hardware revisions, these are not showstoppers for the current prototype design. Implementing these (e.g., conformal coating, schematic restructuring) was explicitly decided against for this iteration.

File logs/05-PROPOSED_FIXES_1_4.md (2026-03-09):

# Proposed Fixes 1–4: Revised Implementations

**Last modified: 2026-03-09 06:35**

*Fixes derived from CODEBASE_REVIEW_FINDINGS.md, rewritten against actual source.*

---

## Fix 1 — Reject Commands When Unprovisioned (HIGH)

### Problem

When Guillemot has never been provisioned, `g_psk` is all zeros (loaded from
`k_default_psk` by `load_psk_from_storage`). An attacker who knows the system
uses AES-CCM with a zero key can craft a valid MIC for any counter/command pair.
`verify_payload` will pass because it computes the MAC with the same zero key.

### Why it matters

The zero-key state is deterministic and public (it's a hardcoded constant in
source). Any attacker who reads the firmware or knows the protocol can unlock
the immobilizer on an unprovisioned device.

### Fix

`key_is_all_zeros()` already exists at line 54 of `guillemot/src/main.cpp`.
It is currently only used as the `is_provisioned` callback for
`ensure_provisioned`. The fix is a one-line addition to `scan_callback`:

```cpp
// guillemot/src/main.cpp, lines 151-156
void scan_callback(ble_gap_evt_adv_report_t* report) {
  immo::Payload pl{};
  if (!parse_payload_from_report(report, pl)) return;
  if (key_is_all_zeros()) return;          // <-- ADD THIS LINE
  if (!verify_payload(pl)) return;
  handle_valid_command(pl);
}
```

This reuses the existing function with zero new code. The guard sits before
`verify_payload` so we never even attempt cryptographic verification with a
known-bad key.

### Tradeoff

None. An unprovisioned device has no legitimate fob paired to it, so rejecting
all commands is correct behavior.

---

## Fix 2 — Persist Counter Before Advertising on Uguisu (HIGH)

### Problem

In `uguisu/src/main.cpp` lines 191–194, the current order is:

```
start_advertising_once(...)   // line 191 — begin BLE broadcast
delay(UGUISU_ADVERTISE_MS)    // line 192 — wait for receiver to pick it up
g_store.update(counter)       // line 193 — persist incremented counter
system_off()                  // line 194 — deep sleep
```

If power is lost during the `delay` window (battery dies, user pulls battery,
voltage sag), the counter is never persisted. On next boot, `loadLast()` returns
the same value, the fob reuses the same counter, and the signed payload is
identical — a replay. Guillemot will accept it because `pl.counter > last` still
holds (the receiver saw it and persisted, but the fob didn't).

Worse: if the receiver *also* lost power (both devices on the scooter), the
receiver's counter is also stale, and the replayed payload works again. But even
if only the fob loses power, the fob is now stuck — it will keep generating the
same counter that Guillemot already consumed and will reject.

### Fix

Move `g_store.update(counter)` before the advertising call:

```cpp
// uguisu/src/main.cpp, lines 191-194 become:
g_store.update(counter);                        // persist FIRST
start_advertising_once(MSD_COMPANY_ID, payload13);
delay(UGUISU_ADVERTISE_MS);
system_off();
```

### Tradeoff

If `update()` succeeds but advertising fails (BLE stack error, immediate power
loss before any packet transmitted), the counter is advanced but no command
was delivered. The fob "wastes" one counter value. This is harmless — the user
presses the button again, gets counter+2, and everything works. Counter space
is 2^32, so wasting values is not a concern.

The alternative (counter reuse / replay) is a security and reliability failure.
Wasting a counter value is strictly better.

---

## Fix 3 — Persist Counter Before Actuation on Guillemot (MEDIUM)

### Problem

In `guillemot/src/main.cpp` `handle_valid_command` (lines 130–148):

```cpp
case immo::Command::Unlock:
  latch_set_pulse();                 // physical action — 15ms pulse
  buzzer_tone_ms(BUZZER_UNLOCK_MS);  // blocking buzzer — hundreds of ms
  g_store.update(pl.counter);        // persist counter AFTER
  break;
```

If power is lost after `latch_set_pulse` but before `g_store.update`, the
latch has physically moved (scooter unlocked) but the counter is not persisted.
On next boot, `lastCounter()` returns the old value. The same signed payload
from the fob would be accepted again — but the fob has already advanced its own
counter past this value (assuming fix 2), so the real consequence is:

- The receiver's counter is behind the fob's counter.
- The next legitimate fob press (counter N+1) will still work because N+1 > old.
- But if an attacker captured the BLE advertisement for counter N, they can
  replay it after the power loss because the receiver thinks N is still fresh.

This is a narrower window than fix 2, but `buzzer_tone_ms` blocks for the full
buzzer duration (likely 100–500ms), which is a meaningful power-loss window.

### Fix

Persist counter first, then actuate:

```cpp
void handle_valid_command(const immo::Payload& pl) {
  const uint32_t last = g_store.lastCounter();
  if (pl.counter <= last) return;

  // Persist counter BEFORE physical action
  g_store.update(pl.counter);

  switch (pl.command) {
    case immo::Command::Unlock:
      latch_set_pulse();
      buzzer_tone_ms(BUZZER_UNLOCK_MS);
      break;
    case immo::Command::Lock:
      buzzer_tone_ms(BUZZER_LOCK_MS);
      latch_reset_pulse();
      break;
    default:
      break;
  }
}
```

Note: `g_store.update()` is moved above the switch and called once,
eliminating the duplicated call in each case branch.

### Tradeoff

If `update()` succeeds but power dies before `latch_set_pulse`, the counter is
consumed but the latch didn't move. The user presses the fob again (next
counter), and it works. Same "wasted counter" tradeoff as fix 2 — acceptable.

If `update()` itself fails (flash write error), the function still proceeds
to actuate. Whether this is acceptable depends on your failure philosophy:

- **Option A (current approach above):** Actuate anyway. The device responds
  to the user even if storage is degraded. Risk: counter not persisted, replay
  possible on that one value.
- **Option B (strict):** Check `update()` return value, abort if it fails.
  Requires changing `update()` to return `bool`. Safer but means the device
  stops responding when flash is unhealthy.

I recommend Option A for now (matches current behavior, doesn't require API
changes), with a future enhancement to add a return value to `update()`.

---

## Fix 4 — Exact Checksum Length in Provisioning Parser (MEDIUM)

### Problem

In `immo_provisioning.cpp` line 86:

```cpp
if ((size_t)(col1 - key_hex) != 32 || (size_t)(col2 - counter_hex) != 8 || strlen(checksum_hex) < 4) {
```

`strlen(checksum_hex) < 4` accepts any checksum field of 4 or more characters.
Only the first 4 hex characters are consumed by `hex_byte` calls on lines
104–108. Trailing characters are silently ignored.

This means `PROV:...:...:ABCDgarbage` and `PROV:...:...:ABCD` are treated
identically. While not directly exploitable (the CRC still has to match the
key), it violates the principle of strict parsing: accept exactly what you
expect, reject everything else. Loose parsing invites confusion and makes
protocol evolution harder.

### Fix

Change `<` to `!=`:

```cpp
// immo_provisioning.cpp, line 86
if ((size_t)(col1 - key_hex) != 32 || (size_t)(col2 - counter_hex) != 8 || strlen(checksum_hex) != 4) {
```

That's it. One character change: `<` → `!=`.

The `hex_byte` calls on lines 104–108 already validate that the 4 characters
are valid hex digits (returning false on invalid nibbles), so no additional
hex validation loop is needed.

### Why not a bigger change

The original writeup proposed a 15-line replacement with explicit hex character
validation and restructured field-length checks. This is unnecessary because:

1. Field lengths for key (32) and counter (8) are already validated on the same
   line — no change needed.
2. `hex_byte()` (lines 7–18) already rejects non-hex characters by returning
   `false`, which triggers `ERR:MALFORMED` on lines 106–108.
3. The only actual gap is `< 4` vs `!= 4` for the checksum field.

### File note

This fix applies to `ImmoCommon/src/immo_provisioning.cpp`. If Guillemot and
Uguisu have vendored copies under `lib/ImmoCommon/`, the same one-character
change should be mirrored there.

---

## Summary

| Fix | Severity | Change size | Risk |
|-----|---|---|---|
| 1. Reject unprovisioned commands | HIGH | +1 line | None |
| 2. Uguisu persist-before-advertise | HIGH | Reorder 2 lines | Wasted counter on failed advert (harmless) |
| 3. Guillemot persist-before-actuate | MEDIUM | Move + deduplicate `update()` | Wasted counter on failed actuation (harmless) |
| 4. Strict checksum length | MEDIUM | 1 char change | None |

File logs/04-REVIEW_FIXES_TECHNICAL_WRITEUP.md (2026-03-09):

# Technical Fixes for Codebase Review Findings

**Last modified: 2026-03-09 06:21**

*Proposed solutions for all valid findings from CODEBASE_REVIEW_FINDINGS.md.*

---

## 1. Unprovisioned Receiver (Guillemot) — **HIGH**

**Problem:** Unprovisioned receiver accepts commands; attacker with zero key can craft valid MIC.

**Fix:** Add early return in `scan_callback` before `verify_payload`:

```cpp
void scan_callback(ble_gap_evt_adv_report_t* report) {
  immo::Payload pl{};
  if (!parse_payload_from_report(report, pl)) return;
  if (key_is_all_zeros()) return;  // Reject when unprovisioned
  if (!verify_payload(pl)) return;
  handle_valid_command(pl);
}
```

**File:** `Guillemot/firmware/guillemot/src/main.cpp`

---

## 2. Uguisu Counter Persistence Order — **HIGH**

**Problem:** `g_store.update(counter)` runs after `delay(UGUISU_ADVERTISE_MS)`; power loss during that window causes counter reuse and replay on next boot.

**Fix:** Persist counter before advertising (or at least before the long delay):

```cpp
// Persist first; if storage fails, abort before advertising
g_store.update(counter);
start_advertising_once(MSD_COMPANY_ID, payload13);
delay(UGUISU_ADVERTISE_MS);
system_off();
```

If you need to avoid advancing counter before advertising succeeds, alternative: persist at the *start* of the advertise phase (before `delay`), so the ~2s window is eliminated—worst case is power loss mid-advertise, but counter is already saved.

**File:** `Uguisu/firmware/uguisu/src/main.cpp`

---

## 3. Guillemot Lock/Counter Order — **MEDIUM**

**Problem:** Latch/buzzer actions run before `g_store.update()`. If update fails, physical state changed but counter not persisted; next unlock may be rejected as replay.

**Fix:** Update counter before or as close as possible to the physical action. Option A—update first, then act:

```cpp
case immo::Command::Unlock:
  g_store.update(pl.counter);
  latch_set_pulse();
  buzzer_tone_ms(BUZZER_UNLOCK_MS);
  break;
case immo::Command::Lock:
  g_store.update(pl.counter);
  buzzer_tone_ms(BUZZER_LOCK_MS);
  latch_reset_pulse();
  break;
```

**Caveat:** If `update()` fails, you could add error handling (e.g. retry, abort, or document that failure leaves system in undefined state). Document failure behavior in comments or design doc.

**File:** `Guillemot/firmware/guillemot/src/main.cpp`

---

## 4. Stricter Checksum Validation (immo_provisioning) — **MEDIUM**

**Problem:** `strlen(checksum_hex) < 4` allows trailing garbage; only first 4 hex chars are validated.

**Fix:** Require exactly 4 hex chars. After parsing `checksum_hex`:

```cpp
// Replace: strlen(checksum_hex) < 4
// With: require exactly 4 hex chars
if ((size_t)(col1 - key_hex) != 32 || (size_t)(col2 - counter_hex) != 8) {
  Serial.println("ERR:MALFORMED");
  return false;
}
// Validate checksum is exactly 4 hex chars
const char* checksum_hex = col2 + 1;
if (strlen(checksum_hex) != 4) {
  Serial.println("ERR:MALFORMED");
  return false;
}
for (int i = 0; i < 4; i++) {
  char c = checksum_hex[i];
  if (!((c >= '0' && c <= '9') || (c >= 'a' && c <= 'f') || (c >= 'A' && c <= 'F'))) {
    Serial.println("ERR:MALFORMED");
    return false;
  }
}
```

Or use a helper that returns false if any char after the 4th is non-whitespace/non-null.

**File:** `ImmoCommon/src/immo_provisioning.cpp` (and mirrored copies in Guillemot/Uguisu libs)

---

## 5. Document BLE Scan/Advert Timing — **MEDIUM**

**Problem:** Guillemot 1% duty cycle scan can miss Uguisu adverts; worst-case latency can reach several seconds.

**Fix:** Documentation only. Add to design/architecture docs:

- Guillemot: `SCAN_INTERVAL_MS=2000`, `SCAN_WINDOW_MS=20` (1% duty cycle).
- Uguisu: adverts every ~100 ms for ~2 s.
- Worst-case: if scan window falls between adverts, user may need to hold button and retry; worst-case latency ~2–4 seconds.
- Recommend documenting this in user-facing docs (e.g. “hold fob button for 2–3 seconds near MCU”).

**Files:** `Guillemot/README.md`, `Uguisu/README.md`, or `logs/CODEBASE_TECHNICAL_WRITEUP.md`

---

## 6. ensure_provisioned Timeout Option — **LOW**

**Problem:** When VBUS present and not provisioned, loop runs indefinitely; can block boot when USB plugged but no host connected.

**Fix:** Add optional max attempts or cumulative timeout. For example:

```cpp
void ensure_provisioned(
    uint32_t timeout_ms,
    bool (*on_success)(...),
    void (*load_provisioning)(),
    bool (*is_provisioned)(),
    uint32_t max_attempts = 0  // 0 = infinite (current behavior)
) {
  if (prov_is_vbus_present()) {
    prov_run_serial_loop(timeout_ms, on_success);
    if (load_provisioning) load_provisioning();
  }
  uint32_t attempts = 0;
  while (is_provisioned && !is_provisioned() && prov_is_vbus_present()) {
    if (max_attempts > 0 && ++attempts >= max_attempts) break;
    prov_run_serial_loop(timeout_ms, on_success);
    if (load_provisioning) load_provisioning();
  }
}
```

Callers who need non-blocking behavior can pass e.g. `max_attempts=3`; default `0` preserves current behavior.

**File:** `ImmoCommon/src/immo_provisioning.cpp`

---

## 7. load() Partial-Record Handling — **LOW**

**Problem:** Truncated write could leave half-record; `read` returning partial bytes exits loop but no explicit detection or recovery.

**Fix:** Add basic detection and optional recovery:

```cpp
void CounterStore::load() {
  last_counter_ = 0;
  Adafruit_LittleFS_Namespace::File f(InternalFS.open(log_path_, ...));
  if (!f) return;

  CounterRecord rec{};
  while (true) {
    const size_t n = f.read(reinterpret_cast<void*>(&rec), sizeof(rec));
    if (n == 0) break;
    if (n != sizeof(rec)) {
      // Partial record; stop to avoid using corrupt data
      break;
    }
    if (record_crc(rec.counter) != rec.crc32) continue;
    last_counter_ = rec.counter;
  }
}
```

Optional: if partial read detected, log or set a “dirty” flag for diagnostics. Avoid using the partial record.

**File:** `ImmoCommon/src/immo_storage.cpp`

---

## 8. rotateIfNeeded_ When Log Doesn't Exist — **LOW**

**Problem:** Behavior of `f.size()` when file doesn't exist should be verified.

**Fix:** Adafruit LittleFS `open` with `FILE_O_READ` on non-existent file typically returns invalid/falsy handle; `if (!f) return` already guards. Add an explicit check for clarity:

```cpp
void CounterStore::rotateIfNeeded_() {
  Adafruit_LittleFS_Namespace::File f(InternalFS.open(log_path_, FILE_O_READ));
  if (!f) return;  // File doesn't exist or open failed
  const size_t sz = f.size();
  f.close();
  // ...
}
```

Document in comment: “When log file doesn't exist, open fails and we return early; f.size() is never called.”

**File:** `ImmoCommon/src/immo_storage.cpp`

---

## 9. serial.js: Document No Concurrent Use — **LOW**

**Problem:** Multiple concurrent `readLineWithTimeout` calls resolve in FIFO order; lines can be routed to wrong consumer.

**Fix:** Documentation only. Add to `serial.js` or `Whimbrel` README:

```js
/**
 * readLineWithTimeout: Reads one line with optional timeout.
 * WARNING: Concurrent calls are not supported. Lines are delivered FIFO to
 * the first waiter; use sequentially (e.g. send request → readLine → send next).
 */
```

**File:** `Whimbrel/js/serial.js`

---

## 10. dfu.js: Document Response Matching Fragility — **LOW**

**Problem:** Responses matched by opcode only; some Nordic DFU ops emit multiple responses; out-of-order or duplicate responses could misroute.

**Fix:** Documentation only. Add comment or docblock:

```js
/**
 * receiveResponse: Matches by opcode only. Some Nordic DFU operations
 * (e.g. PRN) may emit multiple responses. Acceptable for standard
 * single-request flows; may misroute in edge cases with concurrent or
 * duplicate responses.
 */
```

**File:** `Whimbrel/js/dfu.js`

---

## Summary Table

| Priority | Issue | Fix Type | Location |
|---|---|---|---|
| High | Unprovisioned receiver | Code | Guillemot main.cpp |
| High | Uguisu counter persistence order | Code | Uguisu main.cpp |
| Medium | Guillemot lock/counter order | Code | Guillemot main.cpp |
| Medium | Stricter checksum validation | Code | immo_provisioning.cpp |
| Medium | BLE scan/advert timing | Docs | Architecture/README |
| Low | ensure_provisioned timeout | Code | immo_provisioning.cpp |
| Low | load() partial-record handling | Code | immo_storage.cpp |
| Low | rotateIfNeeded_ file existence | Code + comment | immo_storage.cpp |
| Low | serial.js concurrency | Docs | serial.js |
| Low | dfu.js response matching | Docs | dfu.js |

---

## Implementation Notes

- **ImmoCommon copies:** Guillemot and Uguisu each have `lib/ImmoCommon`; changes to provisioning/storage should be made in the root `ImmoCommon/` and propagated (or use a single source via submodule/symlink).
- **Testing:** After fixes, verify: (1) unprovisioned Guillemot rejects adverts, (2) Uguisu survives power loss during advertise, (3) provisioning flow still works, (4) lock/unlock with storage failure scenarios if testable.

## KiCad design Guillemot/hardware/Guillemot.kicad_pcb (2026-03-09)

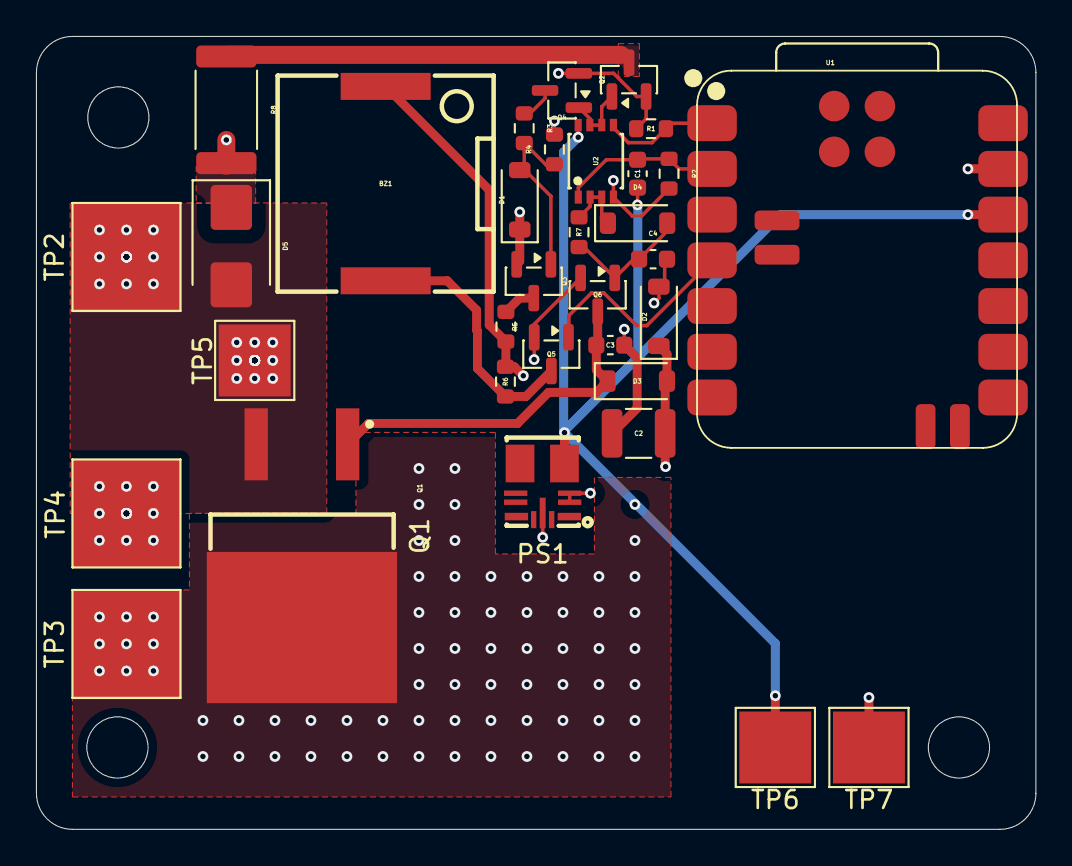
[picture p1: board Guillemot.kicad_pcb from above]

Board: 4 copper layers, 55.5 x 44.0 mm, 33 parts (0 on the bottom side), 17 nets.

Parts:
BZ1: FUET-1230; BUZ-SMD_L12.0-W12.0_FUET-1230
C1: 10nF; C_0603_1608Metric
C2: 100µF; C_1210_3225Metric
C3, C4: 1uF; C_0603_1608Metric
D1: BZT52C12-7-F; D_SOD-123
D2: BZT52C10-7-F; D_SOD-123
D3, D4: 1N4148W; D_SOD-123
D5: SMBJ45A; D_SMB
PS1: TPSM365R6V3RDNR; QFN-11_L4.5-W3.5-P0.50-TL_TPSM365R6FRDNR
Q1: IPB042N10N3G; TO-263-2_L10.0-W9.1-P5.08-LS15.2-TL
Q2: AO3422; SOT-23
Q3: SI2309CDS; SOT-23
Q4: 2N7002; SOT-23
Q5, Q6: MMBT3904; SOT-23
R1, R2, R3, R7: 100k; R_0603_1608Metric
R4: 1M; R_0603_1608Metric
R5: 10k; R_0603_1608Metric
R6: 4.7k; R_0603_1608Metric
R8: 47 2W; R_2512_6332Metric
TP2: BAT-; TestPoint_Pad_6.0x6.0mm
TP3: ESC-; TestPoint_Pad_6.0x6.0mm
TP4: ESC+; TestPoint_Pad_6.0x6.0mm
TP5: WIRE; TestPoint_Pad_4.0x4.0mm
TP6: 3.3V; TestPoint_Pad_4.0x4.0mm
TP7: GND; TestPoint_Pad_4.0x4.0mm
U1: XIAO-nRF52840-SMD
U2: SN74LVC2G02DCTR; MSOP-8_L2.9-W2.8-P0.65-LS4.0-BR

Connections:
+BATT: D1.1 (K), PS1.2 (EN), PS1.3 (VIN), Q3.2 (S), R4.2, TP4.1
/3.3V: C1.2, PS1.4 (VOUT), TP6.1, U1.12 (3V3), U2.8 (VCC)
/10V_RAIL: BZ1.1 (+), C2.1, D2.1 (K), D3.2 (A), R5.2, R6.1
/10V_RAW: Q3.3 (D), R5.1
/BUZZER_SINK: BZ1.2, Q5.3 (C), R6.2
/ESC-: D5.1 (A1), Q1.4 (D), R8.2, TP3.1
/ISO_GATE: C3.1, D3.1 (K), Q1.1 (G), Q6.3 (C)
/MCU_D0: R1.1, U1.1 (P0.02_A0_D0), U2.5 (2A)
/MCU_D1: C1.1, R2.1, U1.2 (P0.03_A1_D1), U2.1 (1A)
/MCU_D3: Q5.1 (B), U1.4 (P0.29_A3_D3)
/NPN_BASE: C4.1, D4.2 (A), Q6.1 (B), R7.2
/PFET_CTRL: Q4.3 (D), R3.1
/PFET_GATE: D1.2 (A), Q3.1 (G), R3.2, R4.1
/PRECHARGE_OUT: Q2.3 (D), R8.1
/QBAR_LOCK: D4.1 (K), R7.1, U2.2 (1B), U2.3 (2Y)
/Q_UNLOCK: Q2.1 (G), Q4.1 (G), U2.6 (2B), U2.7 (1Y)
GND: C2.2, C3.2, C4.2, D2.2 (A), D5.2 (A2), PS1.10 (GND), Q1.3 (S), Q2.2 (S), Q4.2 (S), Q5.2 (E), Q6.2 (E), R1.2, R2.2, TP2.1, TP5.1, TP7.1, U1.13 (GND), U2.4 (GND)

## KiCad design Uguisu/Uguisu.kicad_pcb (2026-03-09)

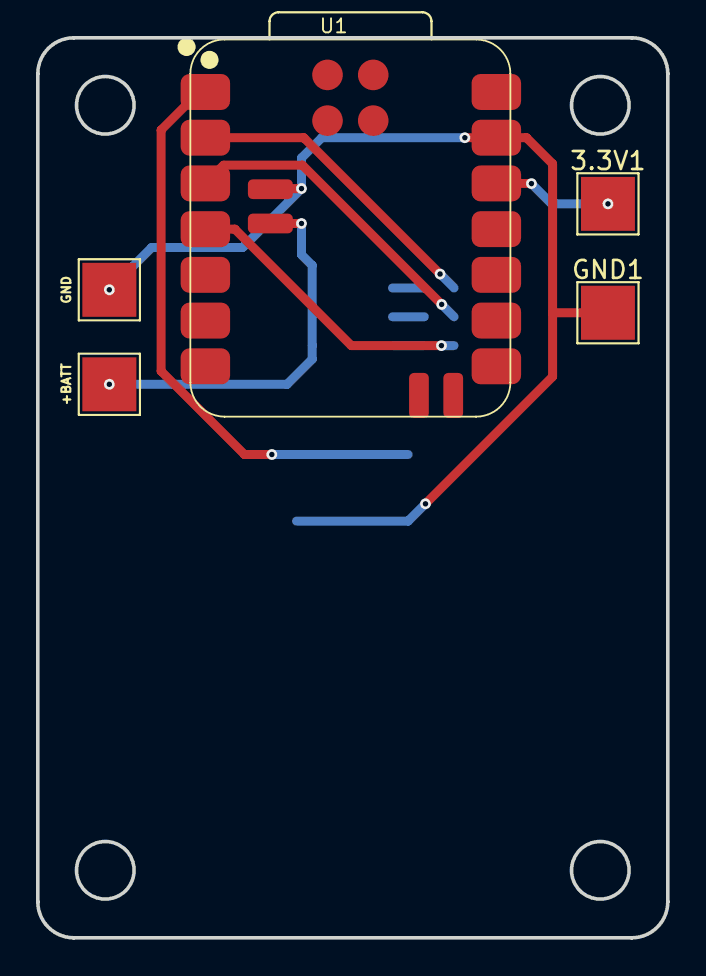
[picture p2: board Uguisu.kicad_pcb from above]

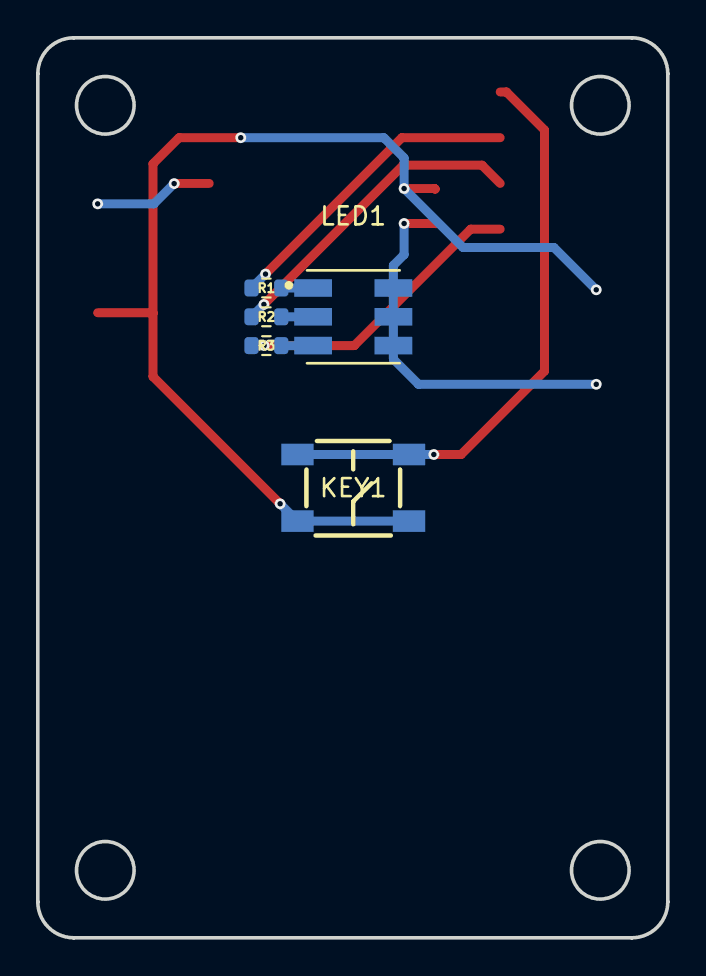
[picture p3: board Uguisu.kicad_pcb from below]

Board: 2 copper layers, 35.0 x 50.0 mm, 10 parts (5 on the bottom side), 10 nets.

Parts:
3.3V1: 3.3V; TestPoint_Pad_3.0x3.0mm
+BATT: +BATT; TestPoint_Pad_3.0x3.0mm
GND, GND1: GND; TestPoint_Pad_3.0x3.0mm
KEY1: SKQGABE010; KEY-SMD_4P-L5.2-W5.2-P3.70-LS6.4
LED1: XL-5050RGBC; LED-ARRAY-SMD_6P-L5.0-W5.0-TL-RD_3
R1, R3: 120; R_0603_1608Metric
R2: 330; R_0603_1608Metric
U1: XIAO-nRF52840-SMD

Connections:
+BATT: +BATT.1, LED1.4 (G+), LED1.5 (R+), LED1.6 (B+), U1.32 (BAT)
/3.3V: 3.3V1.1, U1.12 (3V3)
/MCU_D0: KEY1.1, KEY1.2, U1.1 (P0.02_A0_D0)
/MCU_D1: R1.2, U1.2 (P0.03_A1_D1)
/MCU_D2: R2.2, U1.3 (P0.28_A2_D2)
/MCU_D3: R3.1, U1.4 (P0.29_A3_D3)
GND: GND.1, GND1.1, KEY1.3, KEY1.4, U1.13 (GND), U1.33 (GND)
unnamed: LED1.1 (B-), R1.1
unnamed: LED1.3 (G-), R3.2
unnamed: LED1.2 (R-), R2.1

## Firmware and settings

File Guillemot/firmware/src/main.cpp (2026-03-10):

#include <Arduino.h>

#include <bluefruit.h>
#include <nrf_soc.h>
#include <nrf_wdt.h>

#include <Adafruit_LittleFS.h>
#include <InternalFileSystem.h>

#include "guillemot_config.h"
#include <ImmoCommon.h>

using namespace Adafruit_LittleFS_Namespace;

namespace {

static constexpr const char* COUNTER_LOG_PATH = "/ctr.log";
static constexpr const char* OLD_COUNTER_LOG_PATH = "/ctr.old";

// Runtime key: loaded from flash (Whimbrel-provisioned) or compile-time default.
uint8_t g_psk[16];

immo::CounterStore g_store(COUNTER_LOG_PATH, OLD_COUNTER_LOG_PATH, immo::DEFAULT_COUNTER_LOG_MAX_BYTES);

bool on_provision_success(const uint8_t key[16], uint32_t counter) {
  return immo::prov_write_and_verify(immo::DEFAULT_PROV_PATH, key, counter, g_store, g_psk);
}

static bool key_is_all_zeros() { return immo::is_key_blank(g_psk); }

static void load_psk_from_storage() {
  immo::prov_load_key_or_zero(immo::DEFAULT_PROV_PATH, g_psk);
}

void buzzer_tone_ms(uint16_t hz, uint16_t duration_ms) {
  tone(PIN_BUZZER, hz, duration_ms);
  delay(duration_ms);
  noTone(PIN_BUZZER);
}

bool parse_payload_from_report(ble_gap_evt_adv_report_t* report, uint8_t ct[immo::MSG_LEN], uint8_t mic[immo::MIC_LEN]) {
  uint8_t msd[4 + immo::PAYLOAD_LEN];
  const uint8_t len = Bluefruit.Scanner.parseReportByType(report, BLE_GAP_AD_TYPE_MANUFACTURER_SPECIFIC_DATA, msd, sizeof(msd));
  if (len != sizeof(msd)) return false;

  const uint16_t company_id = static_cast<uint16_t>(msd[0] | (static_cast<uint16_t>(msd[1]) << 8));
  if (company_id != MSD_COMPANY_ID) return false;

  const uint16_t magic = static_cast<uint16_t>(msd[2] | (static_cast<uint16_t>(msd[3]) << 8));
  if (magic != immo::IMMOGEN_MAGIC) return false;

  const uint8_t* p = msd + 4;
  memcpy(ct, p, immo::MSG_LEN);
  memcpy(mic, p + immo::MSG_LEN, immo::MIC_LEN);
  return true;
}

bool verify_payload(const uint8_t ct[immo::MSG_LEN], const uint8_t mic[immo::MIC_LEN], immo::Payload& out_pl) {
  // Extract counter (first 4 bytes of ct, which are unencrypted AAD)
  const uint32_t counter = static_cast<uint32_t>(ct[0] | (static_cast<uint32_t>(ct[1]) << 8) | (static_cast<uint32_t>(ct[2]) << 16) | (static_cast<uint32_t>(ct[3]) << 24));

  uint8_t nonce[immo::NONCE_LEN];
  immo::build_nonce(counter, nonce);

  uint8_t msg[immo::MSG_LEN];
  uint8_t expected[immo::MIC_LEN];
  if (!immo::ccm_auth_decrypt(g_psk, nonce, ct, immo::MSG_LEN, 4, msg, expected)) return false;

  if (!immo::constant_time_eq(expected, mic, immo::MIC_LEN)) return false;

  out_pl.counter = counter;
  out_pl.command = static_cast<immo::Command>(msg[4]);
  memcpy(out_pl.mic, mic, immo::MIC_LEN);
  return true;
}

void handle_valid_command(const immo::Payload& pl) {
  const uint32_t last = g_store.lastCounter();
  if (pl.counter <= last) return;

  g_store.update(pl.counter);

  switch (pl.command) {
    case immo::Command::Unlock:
      latch_set_pulse();
      buzzer_tone_ms(BUZZER_LOW_HZ,  BUZZER_LOW_MS);
      buzzer_tone_ms(BUZZER_HIGH_HZ, BUZZER_HIGH_MS);
      break;
    case immo::Command::Lock:
      buzzer_tone_ms(BUZZER_HIGH_HZ, BUZZER_HIGH_MS);
      buzzer_tone_ms(BUZZER_LOW_HZ,  BUZZER_LOW_MS);
      latch_reset_pulse();
      break;
    default:
      // Ignore unknown commands
      break;
  }
}

void scan_callback(ble_gap_evt_adv_report_t* report) {
  uint8_t ct[immo::MSG_LEN];
  uint8_t mic[immo::MIC_LEN];
  if (!parse_payload_from_report(report, ct, mic)) return;
  if (key_is_all_zeros()) return;
  
  immo::Payload pl{};
  if (!verify_payload(ct, mic, pl)) return;
  handle_valid_command(pl);
}

}  // namespace

void setup() {
  pinMode(PIN_LATCH_SET, OUTPUT);
  pinMode(PIN_LATCH_RESET, OUTPUT);
  pinMode(PIN_BUZZER, OUTPUT);

  digitalWrite(PIN_LATCH_SET, LOW);
  digitalWrite(PIN_LATCH_RESET, LOW);
  noTone(PIN_BUZZER);

  Serial.begin(115200);
  delay(50);

  if (!g_store.begin()) {
    Serial.println("InternalFS begin failed");
    immo::led_error_loop(PIN_ERROR_LED);
  }

  load_psk_from_storage();
  immo::ensure_provisioned(immo::DEFAULT_PROV_TIMEOUT_MS, on_provision_success, load_psk_from_storage, key_is_all_zeros);

  g_store.load();

  Bluefruit.begin(0, 1);
  Bluefruit.setName("Guillemot");

  Bluefruit.Scanner.setRxCallback(scan_callback);
  Bluefruit.Scanner.useActiveScan(false);
  Bluefruit.Scanner.filterMSD(MSD_COMPANY_ID);
  Bluefruit.Scanner.setIntervalMS(SCAN_INTERVAL_MS, SCAN_WINDOW_MS);
  Bluefruit.Scanner.start(0);

  nrf_wdt_behaviour_set(NRF_WDT, NRF_WDT_BEHAVIOUR_RUN_SLEEP);
  nrf_wdt_reload_value_set(NRF_WDT, (8000 * 32768) / 1000); // 8 second timeout
  nrf_wdt_reload_request_enable(NRF_WDT, NRF_WDT_RR0);
  nrf_wdt_task_trigger(NRF_WDT, NRF_WDT_TASK_START);

  Serial.println("Guillemot scanning");
  Serial.print("BOOTED: Guillemot-");
  Serial.println(__TIMESTAMP__);
  Serial.print("HWID: ");
  Serial.print(NRF_FICR->DEVICEID[0], HEX);
  Serial.println(NRF_FICR->DEVICEID[1], HEX);
}

void loop() {
  nrf_wdt_reload_request_set(NRF_WDT, NRF_WDT_RR0);
  sd_app_evt_wait();
}

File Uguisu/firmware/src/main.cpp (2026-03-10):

#include <Arduino.h>

#include <bluefruit.h>

#include <Adafruit_LittleFS.h>
#include <InternalFileSystem.h>

#include "uguisu_config.h"
#include "led_effects.h"
#include <ImmoCommon.h>

using namespace Adafruit_LittleFS_Namespace;

namespace {

static constexpr const char* COUNTER_LOG_PATH = "/ug_ctr.log";
static constexpr const char* OLD_COUNTER_LOG_PATH = "/ug_ctr.old";

// Runtime key: from Whimbrel provisioned flash or compile-time default.
uint8_t g_psk[16];

immo::CounterStore g_store(COUNTER_LOG_PATH, OLD_COUNTER_LOG_PATH, immo::DEFAULT_COUNTER_LOG_MAX_BYTES);

// Callback for provisioning success
bool on_provision_success(const uint8_t key[16], uint32_t counter) {
  return immo::prov_write_and_verify(immo::DEFAULT_PROV_PATH, key, counter, g_store, g_psk);
}

static bool key_is_all_zeros() { return immo::is_key_blank(g_psk); }

static void load_provisioning() {
  immo::prov_load_key_or_zero(immo::DEFAULT_PROV_PATH, g_psk);
}

static TaskHandle_t g_prov_led_task = nullptr;
static void prov_led_task(void*) {
  while (true) { led::prov_pulse(); }
}

void start_advertising_once(uint16_t company_id, const uint8_t payload13[immo::PAYLOAD_LEN]) {
  uint8_t msd[4 + immo::PAYLOAD_LEN];
  msd[0] = static_cast<uint8_t>(company_id & 0xFF);
  msd[1] = static_cast<uint8_t>((company_id >> 8) & 0xFF);
  msd[2] = static_cast<uint8_t>(immo::IMMOGEN_MAGIC & 0xFF);
  msd[3] = static_cast<uint8_t>((immo::IMMOGEN_MAGIC >> 8) & 0xFF);
  memcpy(&msd[4], payload13, immo::PAYLOAD_LEN);

  Bluefruit.Advertising.stop();
  Bluefruit.Advertising.clearData();

  Bluefruit.Advertising.addFlags(BLE_GAP_ADV_FLAGS_LE_ONLY_GENERAL_DISC_MODE);
  Bluefruit.Advertising.addTxPower();
  Bluefruit.Advertising.addName();

  Bluefruit.Advertising.addData(BLE_GAP_AD_TYPE_MANUFACTURER_SPECIFIC_DATA, msd, sizeof(msd));

  Bluefruit.Advertising.setInterval((UGUISU_ADV_INTERVAL_MS * 8 + 4) / 5, (UGUISU_ADV_INTERVAL_MS * 8 + 4) / 5);
  Bluefruit.Advertising.restartOnDisconnect(false);
  Bluefruit.Advertising.start(0);
}

// Waits for button press and release, returns press duration in ms.
// Button is active LOW (INPUT_PULLUP). Returns 0 if timeout.
static uint32_t wait_for_button_press_release(uint32_t timeout_ms) {
  if (digitalRead(UGUISU_PIN_BUTTON) != LOW) {
    // Pin already HIGH. We woke from sleep but user already released.
    // Treat as a very short press (Unlock).
    return 1; 
  }

  const uint32_t deadline = millis() + timeout_ms;
  const uint32_t press_start = millis();

  while (millis() < deadline && digitalRead(UGUISU_PIN_BUTTON) == LOW) {
    if (millis() - press_start >= UGUISU_LONG_PRESS_MS) {
      // Threshold reached, no need to wait for release
      return UGUISU_LONG_PRESS_MS; 
    }
    delay(10);
  }
  return millis() - press_start;
}

}  // namespace

void setup() {
  Serial.begin(115200);
  delay(50);

  led::init();
  pinMode(UGUISU_PIN_BUTTON, INPUT_PULLUP);

  if (!g_store.begin()) {
    Serial.println("InternalFS begin failed");
    led::error_loop(PIN_ERROR_LED);
  }

  load_provisioning();
  if (immo::prov_is_vbus_present()) {
    xTaskCreate(prov_led_task, "prov_led", 128, nullptr, 1, &g_prov_led_task);
  }
  immo::ensure_provisioned(immo::DEFAULT_PROV_TIMEOUT_MS, on_provision_success, load_provisioning, key_is_all_zeros);
  if (g_prov_led_task) {
    vTaskDelete(g_prov_led_task);
    g_prov_led_task = nullptr;
  }
  led::off();

  Serial.print("BOOTED: Uguisu-");
  Serial.println(__TIMESTAMP__);
  Serial.print("HWID: ");
  Serial.print(NRF_FICR->DEVICEID[0], HEX);
  Serial.println(NRF_FICR->DEVICEID[1], HEX);

  Bluefruit.begin();
  Bluefruit.setName("Uguisu");
  Bluefruit.setTxPower(0);

  // Wait for button: single press = Unlock, long press (>= 1s) = Lock
  const uint32_t press_ms = wait_for_button_press_release(UGUISU_BUTTON_TIMEOUT_MS);
  if (press_ms == 0) system_off();  // No press within timeout, sleep
  const immo::Command command =
      (press_ms >= UGUISU_LONG_PRESS_MS) ? immo::Command::Lock : immo::Command::Unlock;
  const uint8_t cmd_pin = (command == immo::Command::Lock) ? PIN_LED_R : PIN_LED_G;
  const bool low_bat = (readVbat_mv() < LED_LOWBAT_MV_THRESHOLD);

  const uint32_t last = g_store.loadLast();
  const uint32_t counter = last + 1;

  uint8_t nonce[immo::NONCE_LEN];
  immo::build_nonce(counter, nonce);

  uint8_t msg[immo::MSG_LEN];
  immo::build_msg(counter, command, msg);

  uint8_t ct[immo::MSG_LEN];
  uint8_t mic[immo::MIC_LEN];
  const bool ok = immo::ccm_auth_encrypt(g_psk, nonce, msg, sizeof(msg), 4, ct, mic);
  if (!ok) system_off();

  uint8_t payload13[immo::PAYLOAD_LEN];
  memcpy(&payload13[0], ct, sizeof(ct));
  memcpy(&payload13[sizeof(ct)], mic, sizeof(mic));

  g_store.update(counter);
  start_advertising_once(MSD_COMPANY_ID, payload13);
  const uint32_t adv_start = millis();

  if (low_bat) {
    led::flash_low_battery(cmd_pin);
  } else {
    led::flash_once(cmd_pin, LED_FLASH_RISE_MS, LED_FLASH_HOLD_MS, LED_FLASH_FALL_MS);
  }

  const uint32_t elapsed = millis() - adv_start;
  if (elapsed < UGUISU_ADVERTISE_MS) {
    delay(UGUISU_ADVERTISE_MS - elapsed);
  }
  system_off();
}

void loop() {}

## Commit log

2026-03-06 Initial Uguisu KiCad project
    Add KiCad project sources with a minimal README and ignore rules for per-user KiCad artifacts.
    [Uguisu.kicad_pcb, Uguisu.kicad_sch]
2026-03-06 Add PROTOCOL.md, Whimbrel provisioning, build fix (TinyUSB/SPI/bonding), config placeholders
    Made-with: Cursor
    [Guillemot.kicad_pcb, Guillemot.kicad_sch]
2026-03-06 Docs: Enrich README with hardware/power details
    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
2026-03-06 Add GPIO wake-from-system-off, document in README; set long press to 1s
    - Configure button pin SENSE before sd_power_system_off() so next press wakes MCU
    - Add UGUISU_PIN_BUTTON_NRF (P0.x) in config for wake; guard with #ifdef
    - README: describe wake via GPIO (hardware SENSE); change long press to 1 second
    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
2026-03-06 Drop device_id across protocol, crypto, storage, provisioning
    - Crypto: MSG_LEN 7→5, PAYLOAD_LEN 11→9, nonce/msg without device_id
    - Storage: CounterRecord(counter,crc32) only; lastCounter(), update(counter), seed(counter)
    - Provisioning: PROV:key:counter:checksum (no device_id)
    - gen_mic.py: remove --device-id, payload 9 bytes
    Breaking: re-provision required for existing devices
    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
2026-03-06 docs: update README BLE payload (9 bytes, no device ID)
    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
2026-03-07 Add default-case comment; update ImmoCommon submodule
    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
2026-03-07 Button D0, RGB LED (LED1), config and README BOM updates
    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
    [Uguisu_bom.csv, Uguisu_designators.csv, Uguisu_positions.csv]
2026-03-07 Restore KiCad schematic and PCB
    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
    [Uguisu.kicad_pcb, Uguisu.kicad_sch]
2026-03-07 docs: update BOM pricing with per-board breakdown and resistor notes
    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
2026-03-07 docs: sort BOM table by reference designator
    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
2026-03-07 LED pin order and docs: D1=Blue, D2=Red, D3=Green; R1=Blue, R2=Red, R3=Green; LED1 pins 1/2/3
    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
    [Uguisu.kicad_pcb, Uguisu.kicad_sch, Uguisu_bom.csv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]
2026-03-07 Update README BOM costs to unit price
    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
2026-03-07 Sync README BOM with JLCPCB review and add fabrication docs
    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
2026-03-08 Fix `File` class naming collision natively
    - Removes fragile Python script (`extra_script.py`) used to intercept framework compilation
    - Updates Uguisu to use shared configuration macro from `ImmoCommon`
    - Disables Mass Storage Class (MSC) via TinyUSB built-in config macro `immo_tusb_config.h`
    - Adds `SPI` dependency to PlatformIO and sets LDF to `deep+`
    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
2026-03-08 fix: strict checksum length in provisioning parser (Fix 4)
    Change strlen(checksum_hex) < 4 to != 4 to reject trailing garbage.
    Accepts exactly 4 hex chars for CRC-16 checksum field.
    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
    [immo_provisioning.cpp]
2026-03-08 fix: reject unprovisioned commands, persist counter before actuation (Fixes 1 & 3)
    - Add key_is_all_zeros() guard in scan_callback to reject commands when
    unprovisioned (prevents zero-key MIC forgery)
    - Persist counter before latch/buzzer in handle_valid_command to avoid
    replay on power loss during actuation
    - Update ImmoCommon submodule for strict checksum length (Fix 4)
    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
    [main.cpp]
2026-03-08 fix: persist counter before advertising (Fix 2)
    - Move g_store.update(counter) before start_advertising_once to avoid
    counter reuse on power loss during advertise delay
    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
    [main.cpp]
2026-03-09 refactor: use ImmoCommon prov/util helpers, normalize PSK storage path
    - on_provision_success: delegate to immo::prov_write_and_verify()
    - load_provisioning: delegate to immo::prov_load_key()
    - PSK storage path changed from /ug_prov.bin to /prov.bin (re-provisioning required)
    - Remove local PROV_MAGIC (now immo::PROV_MAGIC in ImmoCommon)
    - key_is_all_zeros: thin wrapper over immo::is_key_blank()
    - led_error_loop: replaced with immo::led_error_loop(PIN_ERROR_LED)
    - Advertising interval: replace float division (MS/0.625) with integer math
    ((MS*8+4)/5) — no behavior change, avoids FPU on Cortex-M4F
    - bump ImmoCommon submodule to d25e3d9
    [main.cpp]
2026-03-09 refactor: use ImmoCommon shared defaults and prov_load_key_or_zero
    Bump ImmoCommon submodule to b52ef26. Replace local PROV_STORAGE_PATH,
    COUNTER_LOG_MAX_BYTES, PROV_TIMEOUT_MS, and k_default_psk with their
    immo:: counterparts. Simplify load_provisioning() via prov_load_key_or_zero.
    [main.cpp]
2026-03-09 feat: add RGB LED effects with interactive visualizer
    - Add led_effects.h: active-low PWM fade/pulse helpers for all boot states
    (unlock green, lock red, provisioning blue, low-battery pulse, error blink)
    - Add tools/led_visualizer.html: browser-based timing tuner with live preview,
    sync rise/fall toggle, and generated C++ define output
    - Wire led::init(), led::error_loop(), and led_effects.h include into main.cpp
    - Update README with LED behaviour table and complete annotated boot flow
    [main.cpp]
2026-03-09 pcb: adjust routing and via positions
    [Uguisu.kicad_pcb]
2026-03-09 refactor: rename config header to uguisu_nrf52840.h, fix readVbat_mv, move system_off
    - Rename uguisu_config.example.h → uguisu_nrf52840.h to clearly identify it
    as the nRF52840 board-specific defaults
    - Fix readVbat_mv(): toggle VBAT_ENABLE (P0.14) around the ADC read to
    enable the PMOS-gated 1MΩ/1MΩ divider on XIAO nRF52840; add 1 ms settle
    delay; guard with #ifdef for portability
    - Move system_off() from main.cpp into uguisu_nrf52840.h alongside the
    other board-specific hardware functions
    - Drop redundant nrf_gpio.h / nrf_soc.h includes from main.cpp (now
    provided transitively via uguisu_nrf52840.h)
    [main.cpp, uguisu_nrf52840.h]
2026-03-09 tune: set BLE scan timing to 500 ms interval / 20 ms window
    Reduces scan interval from 2000→500 ms and window from 20→20 ms
    (window unchanged) to improve detection latency. Duty cycle rises
    from 1% to 4%, still well within scooter battery budget.
2026-03-09 docs: migration extract + Guillemot/monorepo updates
    - Add logs/14-DETAILED_DOC_EXCLUSIVE_CONTENT.md (EasyEDA→KiCad remains)
    - Guillemot README: PCB layout (pre-charge trace 1.0mm, single-sided SMT),
    design notes (inrush, RC bypass, gate isolation Vgs, gate pull-down,
    MOSFET successor IPB035N10NF2S)
    - Monorepo README: TBD section
    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
2026-03-09 docs: add EasyEDA→KiCad to Guillemot and Uguisu Design Notes
    - 14-DETAILED_DOC: all items ported, update intro
    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
2026-03-09 docs: improve logs/ folder description in README
    Better reflects actual content: technical writeups, architecture reviews,
    power analysis, design decisions, migration guides, and documentation
    reports—not just migration reports.
2026-03-09 Update C2 to EMK325ABJ107MM-P, add no-hardware-edits rule, add codebase docs
    - C2: EMK325ABJ107MM-P 100µF 16V X5R (was CL32A107MPVNNNE 10V)
    - Cursor rule: do not modify files under hardware/
    - Guillemot: KiCad schematic/PCB LCSC C90143, README, matched parts
    - logs/18-CODEBASE_TECHNICAL_DOCUMENTATION.md
    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
    [Guillemot.kicad_pcb, Guillemot.kicad_sch]
2026-03-10 fix(arch): implement approved architecture and UX fixes
    - Added Watchdog Timer (WDT) to Guillemot to recover from firmware hangs
    - Updated button timing thresholds (700ms long press, 2000ms timeout)
    - Improved button UX with early exit on long press and <200ms press handling
    - Fixed LittleFS counter log rotation power-failure vulnerability
    - Added IMMOGEN_MAGIC prefix to MSD payload for better filtering
    - Upgraded payload security from CBC-MAC to AES-CCM CTR-mode encryption
    - Added new architecture critique and implementation summary logs
    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
    [main.cpp, uguisu_nrf52840.h]
2026-03-10 docs: finalize architecture assessments and technical fixes
    [main.cpp, uguisu_nrf52840.h]
2026-03-10 docs: add Pipit companion app architecture and integration requirements
    Pipit app architecture (KMP + native UI), BLE proximity unlock with
    flipped Guillemot-as-advertiser strategy, GATT protocol design, 4-slot
    key management with 6-digit management PIN, brute-force rate limiting,
    provisioning lifecycle (Whimbrel onboarding flow), platform capability
    matrix (Android USB DFU/serial vs iOS BLE-only), and Whimbrel dual-mode
    operation (Web Serial + Web Bluetooth).
2026-03-11 docs: add Pipit UI/UX design session with access tier model and IDENTIFY command
    Complete iterative refinement of Section 10 (UI/UX Architecture) in the master
    doc, including photorealistic 3D Uguisu model as primary home screen interaction,
    camera-first onboarding with particle-effect QR decryption, and stripped-down
    home screen with settings 3D flip transition. Introduces slot-based access tier
    model (Slot 0: Hardware, Slot 1: Owner/full mgmt, Slots 2-3: Guest/lock-unlock
    only) with IDENTIFY command (0x02) for session identity binding. Unencrypted
    guest QR provisioning with default names. Owner/Guest-specific settings panes.
    All key management flows (Provision, Replace, Migration, USB OTG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
